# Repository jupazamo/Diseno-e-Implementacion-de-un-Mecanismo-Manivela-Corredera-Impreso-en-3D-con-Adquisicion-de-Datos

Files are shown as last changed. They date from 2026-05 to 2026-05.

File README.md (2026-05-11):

# Diseño e Implementación de un Mecanismo Biela-Manivela-Corredera Impreso en 3D con Adquisicion de Datos
Diseño, impresión 3D y análisis cinemático de un mecanismo biela-manivela utilizando Arduino (acelerometría) y software de análisis de video (tracker) para la validación de curvas de velocidad y aceleración.

# Análisis Dinámico de un Mecanismo Biela-Manivela-Corredera en 3D

Este repositorio contiene el desarrollo, fabricación y validación experimental de un mecanismo biela-manivela-corredera. El proyecto integra diseño mecánico, impresión 3D, electrónica con Arduino y análisis de video por computadora.

## 1. Fundamento Teórico

El mecanismo de **biela-manivela-corredera** es un sistema de eslabonamiento diseñado para transformar el movimiento circular en movimiento lineal alternativo o viceversa.

### Definición Técnica
Es un mecanismo de cuatro barras donde uno de los eslabones (la corredera) tiene una articulación de pasador en un extremo y una articulación de deslizamiento (prismática) respecto al eslabón fijo. En este proyecto, el mecanismo se compone de:

1.  **Manivela:** El eslabón que realiza una rotación completa de 360°.
2.  **Biela:** El eslabón que conecta la manivela con la corredera.
3.  **Corredera:** El eslabón que realiza el movimiento de traslación lineal.

## 2. Modelado y Simulación Cinemática

Se realizó el modelado tridimensional y el análisis de movimiento del mecanismo. Esta fase permitió validar el comportamiento dinámico y ajustar las medidas de los eslabones.

### Referencias de Diseño
Para el desarrollo del modelo en SolidWorks, se tomaron como base metodológica los siguientes recursos:

* **Análisis Cinemático - Referencia 1:** [Mecanismo biela - manivela - corredera | Análisis cinemático | SolidWorks](https://youtu.be/6QLbw1xS8sg?si=8fuSzFIXMK4U_QsU)
* **Análisis Cinemático - Referencia 2:** [Simulación de movimiento en Solidworks. Mecanismo biela-manivela](https://youtu.be/_ggUQRI91M0?si=aOPVly7H2sfQ7lVz)

### Simulación en Autodesk Inventor
Se contó con una simulación base configurada a una velocidad angular de **150 RPM (942 deg/s)**, cortesía del **Prof. Efraín Terán**. A partir de este modelo, se obtuvieron las curvas de aceleración características para el punto central de la biela.

<div align="center">
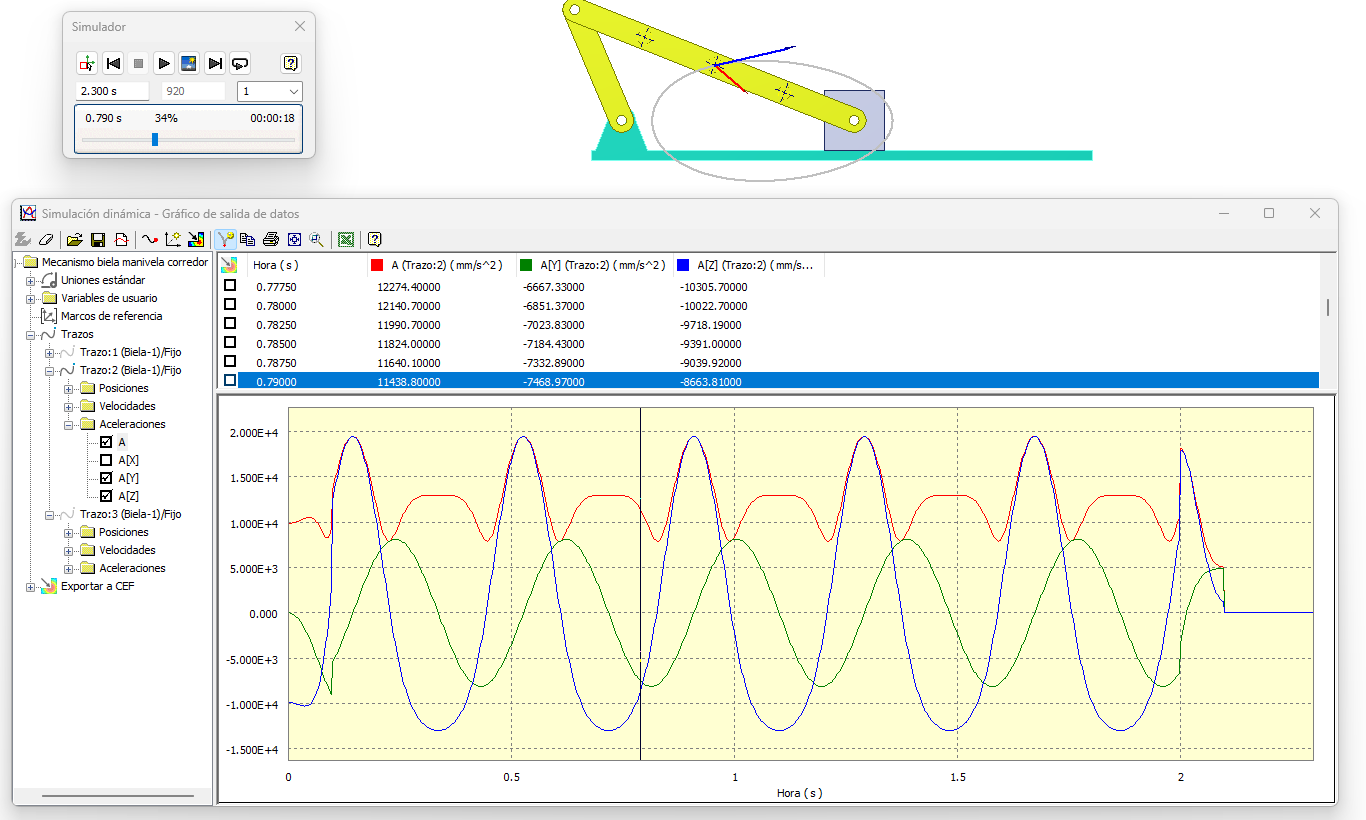
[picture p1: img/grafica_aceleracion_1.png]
Gráfica de Aceleracion 1 - Simulación Inventor
  
  <p><i>Figura 1: Curvas de aceleración del punto central de la biela (Referencia: Prof. Efraín Terán).</i></p>
</div>

<div align="center">
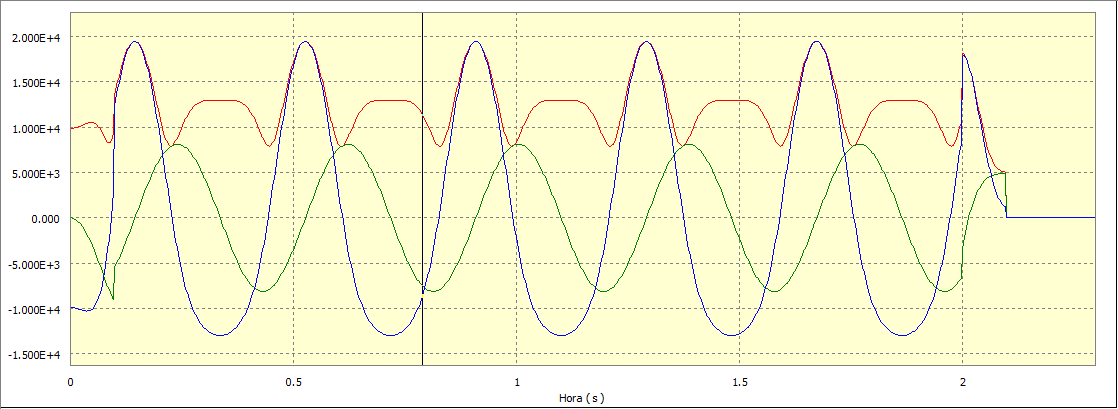
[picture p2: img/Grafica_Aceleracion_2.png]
Gráfica de Aceleración 2 - Simulación Inventor
  
  <p><i>Figura 2: Curvas de aceleración del punto central de la biela (Referencia: Prof. Efraín Terán).</i></p>
</div>

> **Nota aclaratoria:** La simulación original se desarrolló con dimensiones menores a las del prototipo final impreso en 3D. Sin embargo, se mantiene la orientación y tendencia de las curvas cinemáticas como patrón de comparación para las pruebas experimentales.

## 3. Fabricación e Impresión 3D

En esta sección se detallan las consideraciones tomadas para la materialización física del mecanismo. El diseño original fue escalado y modificado para asegurar la funcionalidad mecánica y la facilidad de montaje.

### Archivos de Diseño (CAD)
Los archivos necesarios para la fabricación y edición se encuentran en la carpeta `/cad` del repositorio, organizados de la siguiente manera:

* **Formatos Originales:** Archivos de pieza y ensamble en **SolidWorks 2025**.
* **Formatos de Intercambio (.STEP):** Archivos compatibles con otros softwares de CAD como **Autodesk Inventor**, facilitando su uso académico.

<div align="center">
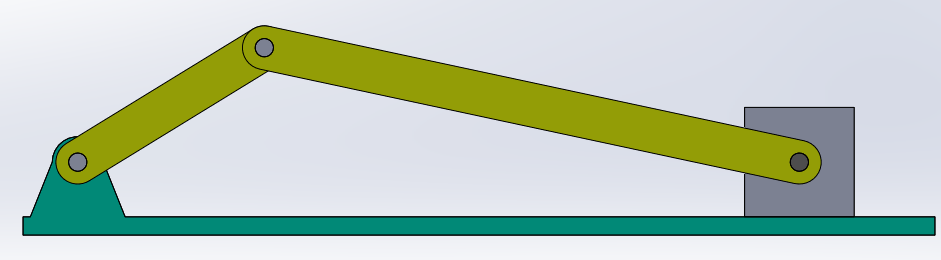
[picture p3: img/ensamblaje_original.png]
Ensamblaje Original en SolidWorks
  
  <p><i>Figura 3: Vista del ensamblaje original diseñado en SolidWorks 2025.</i></p>
</div>

### Archivos Optimizados (Versión Final)
Se incluyen las versiones finales de las piezas.

Para asegurar la compatibilidad y facilitar futuras modificaciones, cada componente optimizado se encuentra disponible en dos formatos dentro de la carpeta `/cad/optimizados`:

* **Formato Nativo (.SLDPRT):** Archivos originales de **SolidWorks 2025**.
* **Formato de Intercambio (.STEP):** Archivos universales compatibles con **Autodesk Inventor**, Fusion 360 y otros sistemas CAD.

<div align="center">
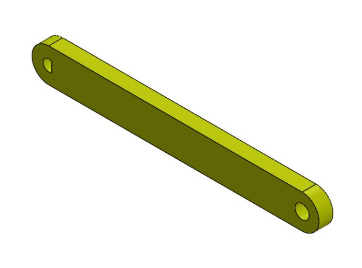
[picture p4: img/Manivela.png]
Manivela
  
  <p><i>Figura 4: Manivela optimizada para acople con motor.</i></p>
</div>

<div align="center">
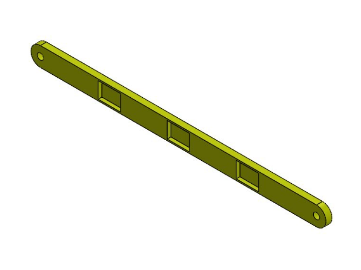
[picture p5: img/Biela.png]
Biela
  
  <p><i>Figura 5: Biela con ajuste de tolerancia en los nodos de articulación.</i></p>
</div>

<div align="center">
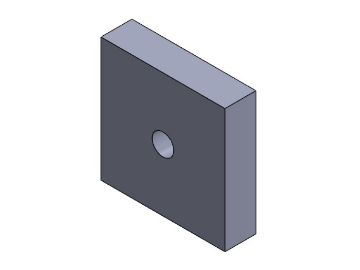
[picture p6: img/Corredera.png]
Corredera
  
  <p><i>Figura 6: Corredera (Pistón) diseñada para deslizamiento de baja fricción.</i></p>
</div>

<div align="center">
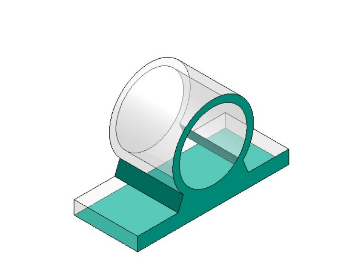
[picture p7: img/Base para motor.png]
Base para motor
  
  <p><i>Figura 7: Soporte estructural para el motorreductor/actuador.</i></p>
</div>

<div align="center">
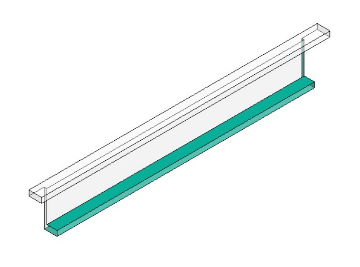
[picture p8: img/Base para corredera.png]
Base para corredera
  
  <p><i>Figura 8: Guía lineal para el desplazamiento de la corredera.</i></p>
</div>

### Resultado Final (Prototipo Físico)

Tras el proceso de impresión y ajuste manual, este es el resultado del mecanismo ensamblado y funcional:

<div align="center">
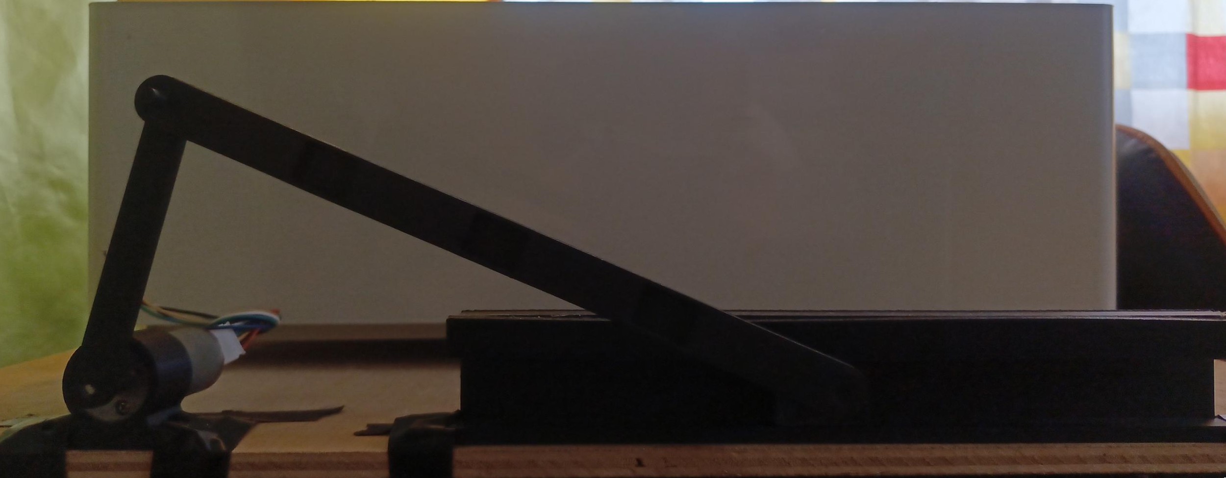
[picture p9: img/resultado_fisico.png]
Mecanismo Fisico
  
  <p><i>Figura 9: Prototipo final impreso en 3D.</i></p>
</div>

#### Demostración de Funcionamiento
El siguiente video muestra el mecanismo en operación .

<div align="center">
  <a href="https://youtu.be/3m06ar881s8">
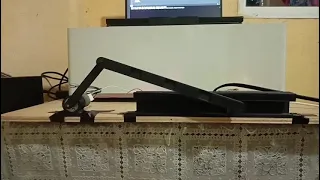
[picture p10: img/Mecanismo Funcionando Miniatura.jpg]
Haz clic para ver el video
    
  </a>
  <p><i>Video 1: Funcionamiento del mecanismo a máxima velocidad utilizando un puente H.</i></p>
</div>

> **Nota Técnica sobre el Sistema de Potencia:** > Durante las pruebas se observó que al alimentar el motor a **12 VDC** (su voltaje máximo nominal) a través del puente H, existe una caída de tensión de aproximadamente **2V** inherente al driver. Por lo tanto, la velocidad observada en el video no representa la velocidad máxima teórica del motor. 
> 
> **Recomendación:** Para futuros ensayos que requieran variar la velocidad angular de forma precisa o alcanzar el límite nominal, se recomienda el uso de una **fuente regulable de laboratorio** para compensar las caídas de tensión del circuito de control.

### Ajuste de Tolerancias y Montaje
Un aspecto crítico del proyecto fue el ajuste de las dimensiones de los agujeros y ejes para permitir una articulación fluida. 

> **Nota técnica sobre impresión 3D:** Debido a las variaciones en la precisión de las impresoras 3D (contracción del material y resolución de ejes), las dimensiones de los acoples fueron optimizadas mediante un proceso de **prueba y error**. 
> 
> * Se realizaron múltiples iteraciones de impresión para ajustar los diámetros internos de los alojamientos de los pasadores.
> * Se recomienda al usuario verificar la calibración de su impresora antes de proceder con la fabricación completa.

## 4. Metodología Experimental: Adquisición de Datos

Para validar el comportamiento del mecanismo impreso en 3D, se implementó un sistema de adquisición de datos dual que permite contrastar los resultados físicos con los modelos teóricos.

---

### 4.1. Acelerometría (Hardware)

Se utilizó un sistema electrónico basado en hardware abierto para medir las variaciones de aceleración de la corredera en tiempo real.

#### Materiales Utilizados
* **Microcontrolador:** Arduino UNO.
* **Sensor:** IMU LSM6DS3 (Acelerómetro y Giróscopo).
* **Actuador:** Motorreductor con Encoder integrado.

<div align="center">
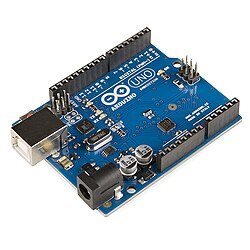
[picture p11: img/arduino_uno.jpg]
Arduino UNO
  
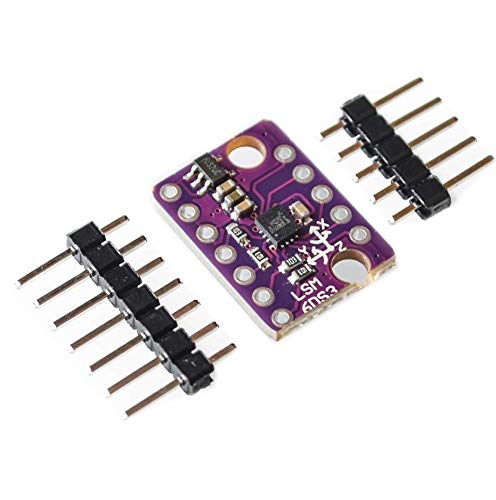
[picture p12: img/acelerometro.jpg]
  
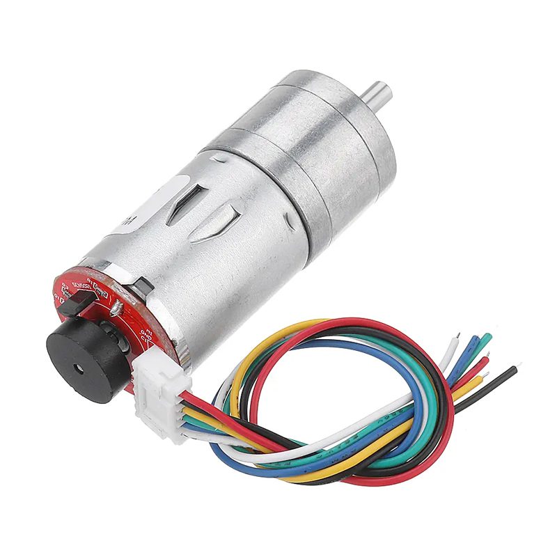
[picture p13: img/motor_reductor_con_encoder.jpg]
  
  <p><i>Figura 10: Componentes electrónicos principales para la captura de datos.</i></p>
</div>

#### Conexión del Motor y Encoder
El motor cuenta con un encoder integrado para el monitoreo de la velocidad angular. A continuación se detalla la configuración de pines:

<div align="center">
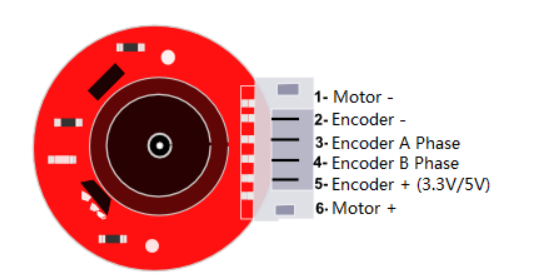
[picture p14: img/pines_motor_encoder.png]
Pines Motor Encoder
  
  <p><i>Figura 11: Diagrama de pines y conexiones del motor con encoder.</i></p>
</div>

### 4.2. Firmware y Software de Procesamiento

El sistema se divide en una etapa de captura (Arduino) y una de procesamiento/visualización (MATLAB/Python). Los códigos se encuentran en la carpeta `/src`.

#### A. Adquisición IMU con Arduino (`/src/arduino`)
El programa utiliza el sensor **LSM6DS3** para adquirir la velocidad angular (Z) y aceleración (X, Y, Z).
* **Calibración:** Realiza un ajuste inicial de *bias* del giróscopo para reducir la deriva.
* **Muestreo:** Frecuencia aproximada de **200 Hz**.
* **Salida:** Formato CSV vía serial (115200 baudios): `t_ms, gz_dps, ax_g, ay_g, az_g`.

#### B. Visualización en Tiempo Real (`/src/matlab` y `/src/python`)
Se desarrollaron scripts para recibir y procesar los datos CSV en vivo.
* **Conversión de Unidades:** De $g$ a $mm/s^2$ (utilizando $1g = 9806.65 mm/s^2$).
* **MATLAB (v. 2025):** Utiliza `serialport` y `animatedline` para gráficas dinámicas.
    * *Nota:* Debido al uso de la versión 2025, versiones anteriores podrían requerir ajustes de compatibilidad en la comunicación serial.
* **Python:** Alternativa **Open Source** que utiliza `pyserial`, `numpy` y `pyqtgraph` para un procesamiento eficiente sin requerir licencias pagadas.

### 4.3. Resultados con Acelerometro

#### Funcionamiento en Tiempo Real
Vídeo del mecanismo operando con la telemetría activa:

<div align="center">
  <a href="https://youtu.be/f9dqSxW6Emg">
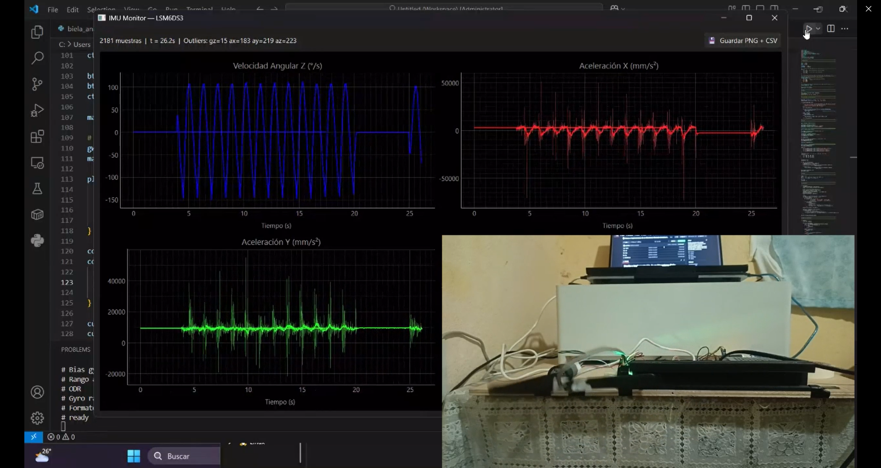
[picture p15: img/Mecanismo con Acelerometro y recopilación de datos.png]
Video de Funcionamiento
    
  </a>
  <p><i>Video 2: Demostración del prototipo y captura de señales en vivo.</i></p>
</div>

#### Gráficas
A continuación se presentan las curvas de velocidad aceleración obtenidas experimentalmente:

<div align="center">
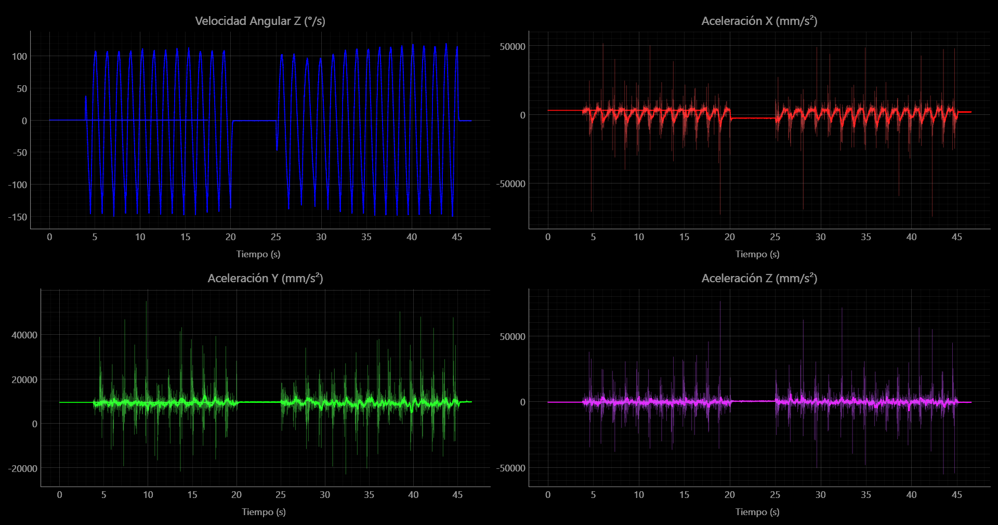
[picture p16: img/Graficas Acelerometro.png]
Gráficas de Resultados con IMU
  
  <p><i>Figura 12: Graficas de resultados obtenidas mediante IMU y Arduino UNO</i></p>
</div>

#### Datos Experimentales (Raw Data)
Para fines de análisis detallado posterior, se han incluido los archivos de datos brutos obtenidos directamente del puerto serial:

* **Archivo:** `/data/datos_acelerometro.csv`
* **Formato:** CSV (Valores separados por comas) con la estructura `t_s,gz_filt_dps,ax_filt_mms2,ay_filt_mms2,az_filt_mms2,ax_raw_mms2,ay_raw_mms2,az_raw_mms2`.

---

### 4.4. Análisis de Video (Software - Tracker)

Como segundo método de validación, se utilizó el software de código abierto **Tracker**, una herramienta de análisis de video y modelado físico construida sobre la plataforma Java Open Source Physics (OSP).

#### Herramientas y Recursos
* **Software:** [Tracker Video Analysis and Modeling Tool](https://physlets.org/tracker/)
* **Metodología de Análisis:** Seguimiento de trayectoria (*Point Mass*) sobre un punto en la biela.
* **Recursos de Referencia:**
    * [Tutorial Base (Péndulo)](https://www.youtube.com/watch?v=l8HXMcte-xs)
    * [Playlist Guía - Prof. Carlos Cuenca](https://youtube.com/playlist?list=PL3bRjIIlh87pTWCi-JaqFhHVurVqUTbHe&si=bdEIOeP9XlYolLrk)

#### Procedimiento de Análisis
1. **Calibración:** Se estableció una vara de calibración en el video basada en una dimensión conocida del mecanismo impreso (longitud de la bancada).
2. **Definición de Ejes:** Se situó el origen de coordenadas en el centro de rotación de la manivela.
3. **Tracking:** Se realizó un seguimiento cuadro a cuadro del **punto central de la biela**.
4. **Derivación Numérica:** El software calculó automáticamente la velocidad y aceleración a partir de los datos de posición.

### 4.5. Resultados con Tracker

### Video del Mecanismo en Funcionamiento
El siguiente video muestra el mecanismo en operación, el cual fue utilizado para el procesamiento en Tracker:

<div align="center">
  <a href="https://youtu.be/3AulUZqwMnk">
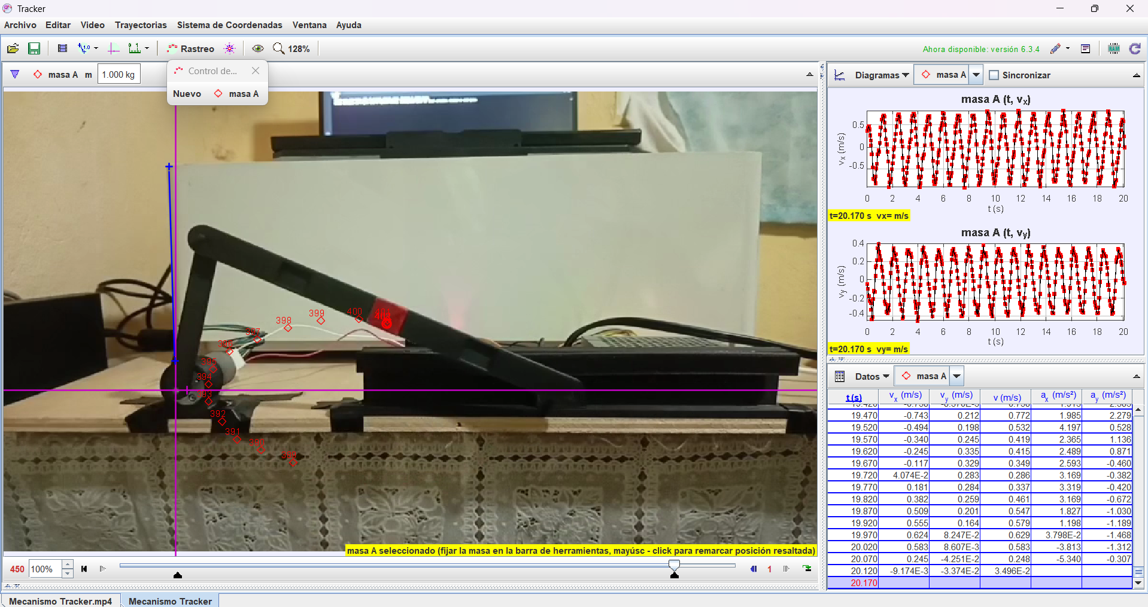
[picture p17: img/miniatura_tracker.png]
Video Funcionamiento Tracker
    
  </a>
  <p><i>Video 3: Captura del mecanismo para análisis cinemático por video.</i></p>
</div>

### Gráficas Resultantes (Tracker)
A continuación se presentan las gráficas de cinemática generadas por el software Tracker, donde se observa el comportamiento del desplazamiento, velocidad y aceleración de la biela:

<div align="center">
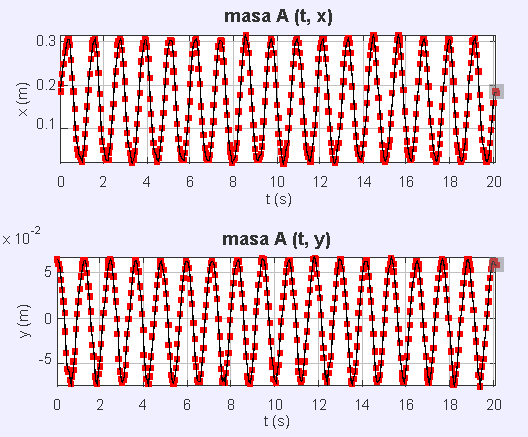
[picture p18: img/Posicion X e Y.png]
  
  <p><i>Figura 13: Curvas de posición obtenidas mediante análisis de video.</i></p>
</div>

<div align="center">
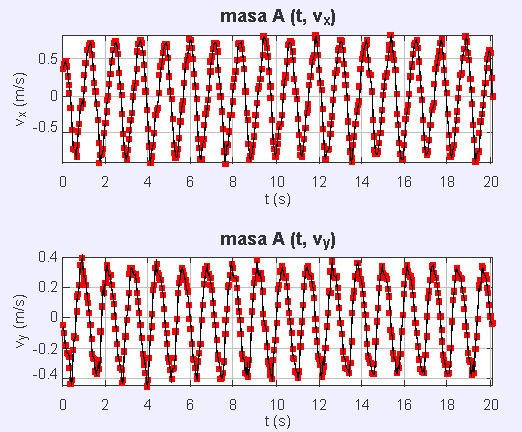
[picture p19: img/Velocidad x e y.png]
  
  <p><i>Figura 14: Curvas de velocidad obtenidas mediante análisis de video.</i></p>
</div>

<div align="center">
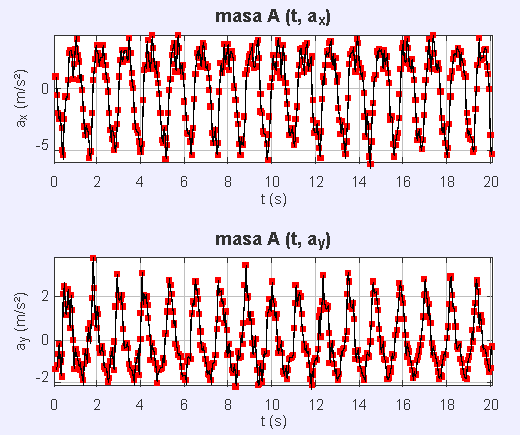
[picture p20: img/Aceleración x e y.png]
  
  <p><i>Figura 15: Curvas de aceleración obtenidas mediante análisis de video.</i></p>
</div>

<div align="center">
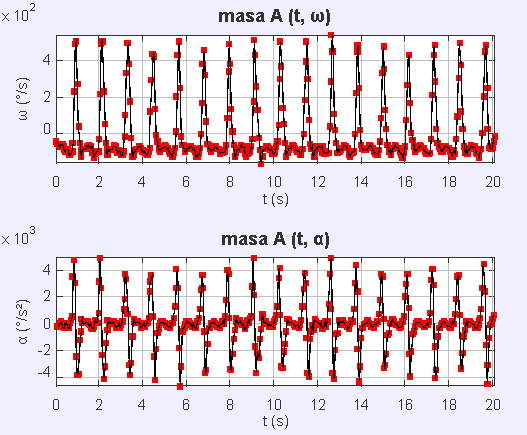
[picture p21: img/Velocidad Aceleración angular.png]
  
  <p><i>Figura 16: Curvas de velocidad y aceleración angular obtenidas mediante análisis de video.</i></p>
</div>

### 4.6. Recursos para Análisis desde Cero
Para facilitar la verificación de los resultados o permitir que otros estudiantes realicen su propia práctica de análisis cinemático, se han incluido los archivos fuente originales:

* **Video Original:** `Mecanismo_Funcionamiento_Tracker.mp4` (Video utilizado para el seguimiento). 
> **Nota aclaratoria:** La longitud de referencia que se muestra en el video es de 0.170 m, pueden usar la misma referencia para su respectivo análisis. 
* **Archivo de Proyecto:** `Mecanismo Tracker.trz` (Contiene la calibración, ejes y puntos de masa ya configurados).

---

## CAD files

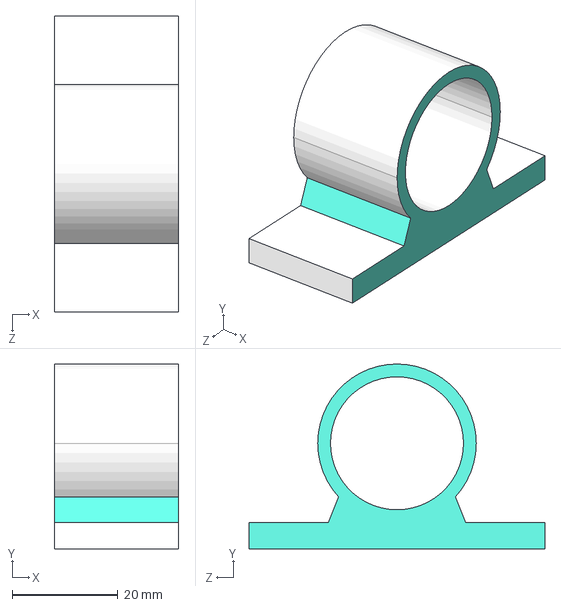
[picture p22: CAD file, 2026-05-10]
cad/optimizados/Base Motor/base_motor.STEP
23.5 x 35.0 x 56.0 mm

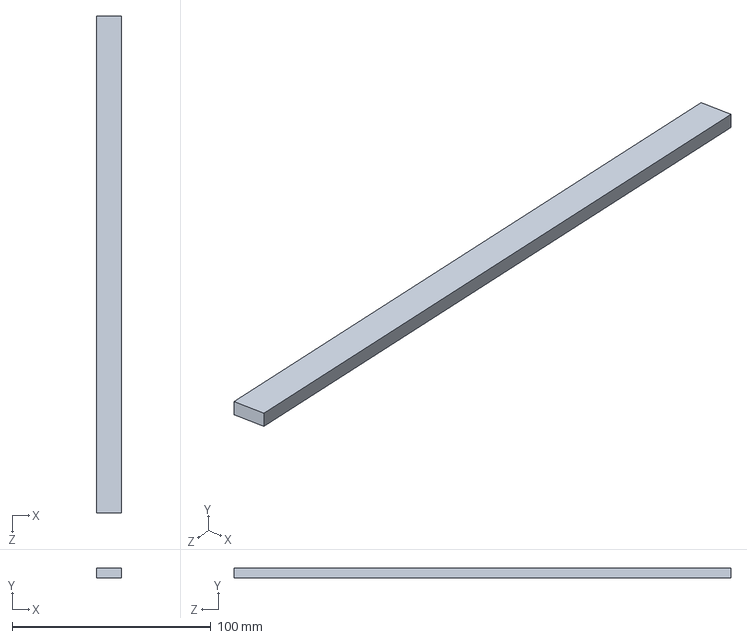
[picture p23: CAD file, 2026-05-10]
cad/optimizados/Base para Corredera/Soporte Superior para base para Corredera.SLDPRT
12.5 x 5.00 x 250.0 mm

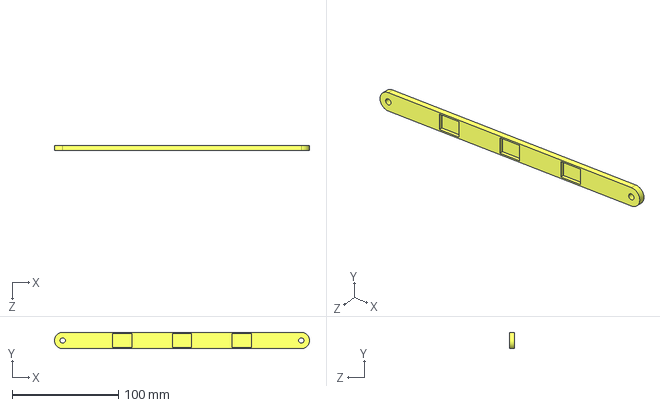
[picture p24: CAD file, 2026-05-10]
cad/optimizados/Biela/Biela.STEP
240.5 x 15.5 x 5.00 mm

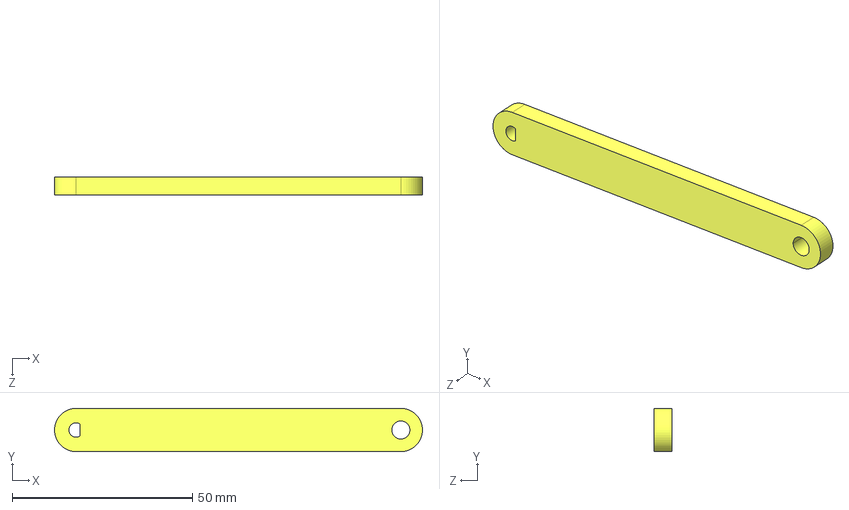
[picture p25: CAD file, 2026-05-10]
cad/optimizados/Manivela/Manivela.STEP
102.0 x 12.0 x 5.00 mm

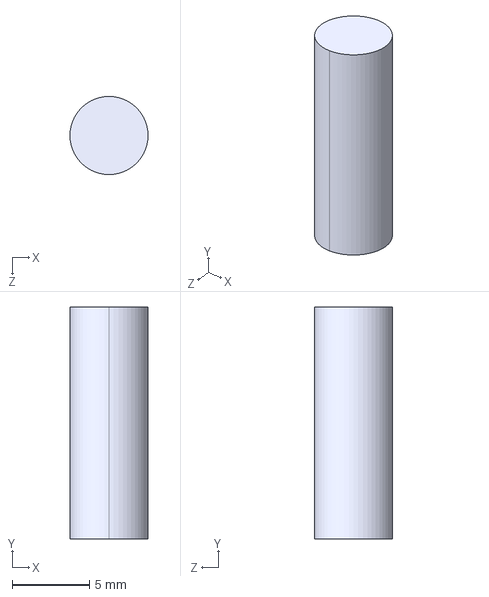
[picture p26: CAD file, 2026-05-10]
cad/optimizados/Pin1 - Biela/pin.STEP
5.05 x 15.0 x 5.05 mm

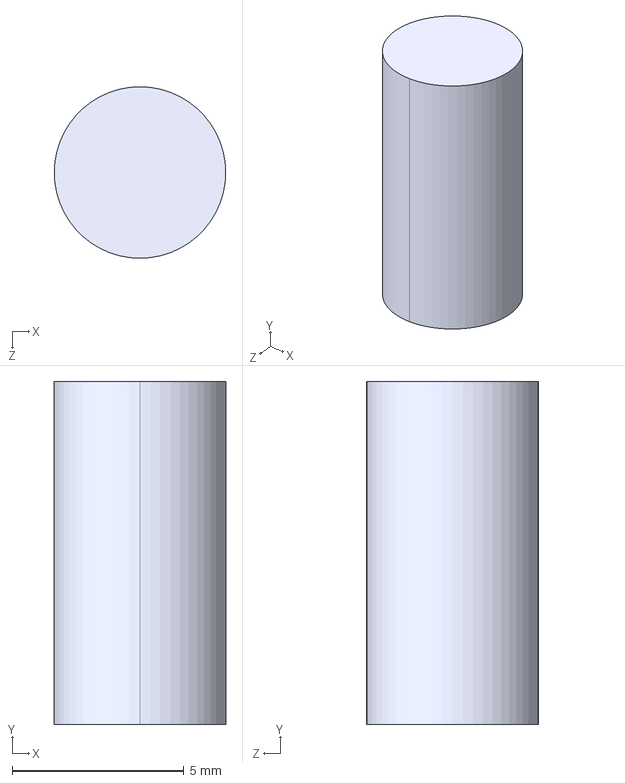
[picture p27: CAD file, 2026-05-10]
cad/optimizados/Pin2 - Manivela/pin -2.STEP
5.00 x 10.0 x 5.00 mm

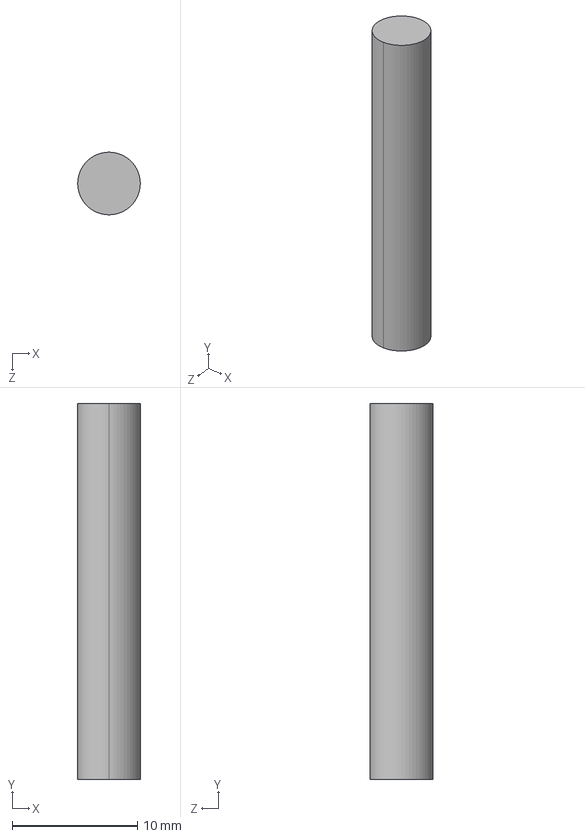
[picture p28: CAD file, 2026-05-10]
cad/optimizados/Pin3 - Corredor/pin - 3.STEP
5.00 x 30.0 x 5.00 mm

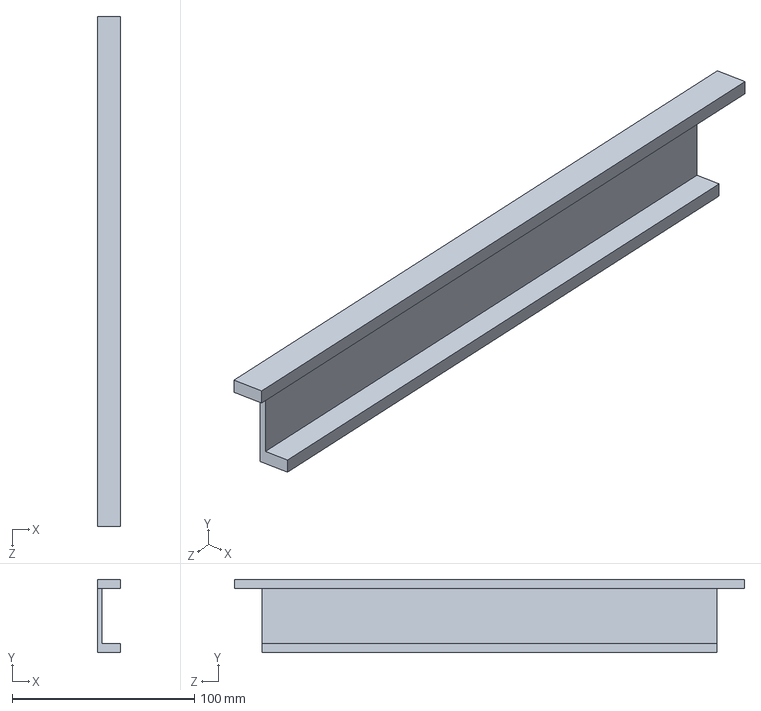
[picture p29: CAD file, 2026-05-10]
cad/optimizados/Base para Corredera/Base para Corredera.SLDPRT
12.5 x 40.3 x 280.0 mm

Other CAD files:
cad/optimizados/Base Motor/base_motor.SLDPRT
cad/optimizados/Biela/Biela.SLDPRT
cad/optimizados/Corredor/corredor.SLDPRT
cad/optimizados/Manivela/Manivela.SLDPRT
cad/optimizados/Pin1 - Biela/pin.SLDPRT
cad/optimizados/Pin2 - Manivela/pin -2.SLDPRT
cad/optimizados/Pin3 - Corredor/pin - 3.SLDPRT

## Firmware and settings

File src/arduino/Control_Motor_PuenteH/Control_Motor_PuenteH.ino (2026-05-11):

// Pines
const int ENB = 3;   // PWM
const int IN3 = 5;
const int IN4 = 4;

void setup() {
  pinMode(ENB, OUTPUT);
  pinMode(IN3, OUTPUT);
  pinMode(IN4, OUTPUT);
}

void loop() {

  // Adelante
  adelante(200);
  delay(3000);

  // Stop
  detener();
  delay(1000);

  // Atrás
  atras(200);
  delay(3000);

  // Stop
  detener();
  delay(1000);
}

// =======================

void adelante(int velocidad) {
  digitalWrite(IN3, HIGH);
  digitalWrite(IN4, LOW);
  analogWrite(ENB, velocidad);
}

void atras(int velocidad) {
  digitalWrite(IN3, LOW);
  digitalWrite(IN4, HIGH);
  analogWrite(ENB, velocidad);
}

void detener() {
  digitalWrite(IN3, LOW);
  digitalWrite(IN4, LOW);
  analogWrite(ENB, 0);
}

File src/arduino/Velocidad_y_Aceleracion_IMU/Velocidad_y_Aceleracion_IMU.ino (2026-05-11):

#include "SparkFunLSM6DS3.h"
#include "Wire.h"

LSM6DS3 imu(I2C_MODE, 0x6B);
float gBiasZ = 0;

// ─────────────────────────────────────────────
// REGISTRO CTRL1_XL (0x10) del LSM6DS3
//
//  bits [7:4]  ODR_XL  → 0101 = 208 Hz
//  bits [3:2]  FS_XL   → 01   = ±16g   ← CAMBIO CLAVE
//  bits [1:0]  LPF     → 00
//
//  0101 01 00 = 0x54
// ─────────────────────────────────────────────
#define CTRL1_XL        0x10
#define ODR_208HZ_16G   0x54   // 208 Hz + ±16g

void calibrateGyroZ(unsigned long ms = 2000) {
  double sum = 0;
  unsigned long n = 0;
  unsigned long t0 = millis();
  while (millis() - t0 < ms) {
    sum += imu.readFloatGyroZ();
    n++;
    delay(2);
  }
  gBiasZ = sum / n;
  Serial.print("# Bias gyro Z: ");
  Serial.print(gBiasZ, 4);
  Serial.println(" °/s");
}

void setup() {
  Serial.begin(115200);
  delay(1500);

  if (imu.begin() != 0) {
    Serial.println("# ERROR: LSM6DS3 no encontrado");
    while (1);
  }

  // Configurar acelerómetro: 208 Hz + ±16g
  imu.writeRegister(CTRL1_XL, ODR_208HZ_16G);
  delay(100);

  // Verificar que se escribió correctamente
  uint8_t reg_val = 0;
  imu.readRegister(&reg_val, CTRL1_XL);
  Serial.print("# CTRL1_XL = 0x");
  Serial.print(reg_val, HEX);
  if (reg_val == ODR_208HZ_16G) {
    Serial.println("  ✓ Rango ±16g confirmado");
  } else {
    Serial.println("  ✗ ERROR: valor inesperado");
  }

  delay(200);
  Serial.println("# Calibrando gyro Z, mantener en reposo...");
  calibrateGyroZ(2000);

  Serial.println("# Rango accel : ±16g");
  Serial.println("# ODR         : 208 Hz");
  Serial.println("# Gyro rango  : ±2000 °/s (default)");
  Serial.println("# Formato     : t_ms,gz_dps,ax_g,ay_g,az_g");
  Serial.println("# ready");
}

void loop() {
  unsigned long t = millis();

  float gz = imu.readFloatGyroZ() - gBiasZ;
  float ax = imu.readFloatAccelX();
  float ay = imu.readFloatAccelY();
  float az = imu.readFloatAccelZ();

  Serial.print(t);
  Serial.print(",");
  Serial.print(gz, 4);
  Serial.print(",");
  Serial.print(ax, 4);
  Serial.print(",");
  Serial.print(ay, 4);
  Serial.print(",");
  Serial.println(az, 4);

  delay(5); // ~200 Hz
}

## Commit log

2026-05-10 Graficas de Aceleracion en Inventor
2026-05-10 Imagenes de diseños finales optimizados
